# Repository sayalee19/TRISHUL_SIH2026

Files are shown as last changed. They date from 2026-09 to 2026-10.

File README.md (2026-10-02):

## Ready Prototype Images
<table width="100%" style="border-collapse: collapse; border: none;">
  <tr>
    <!-- Left Image and Caption -->
    <td align="left" style="border: none; width: 50%;">
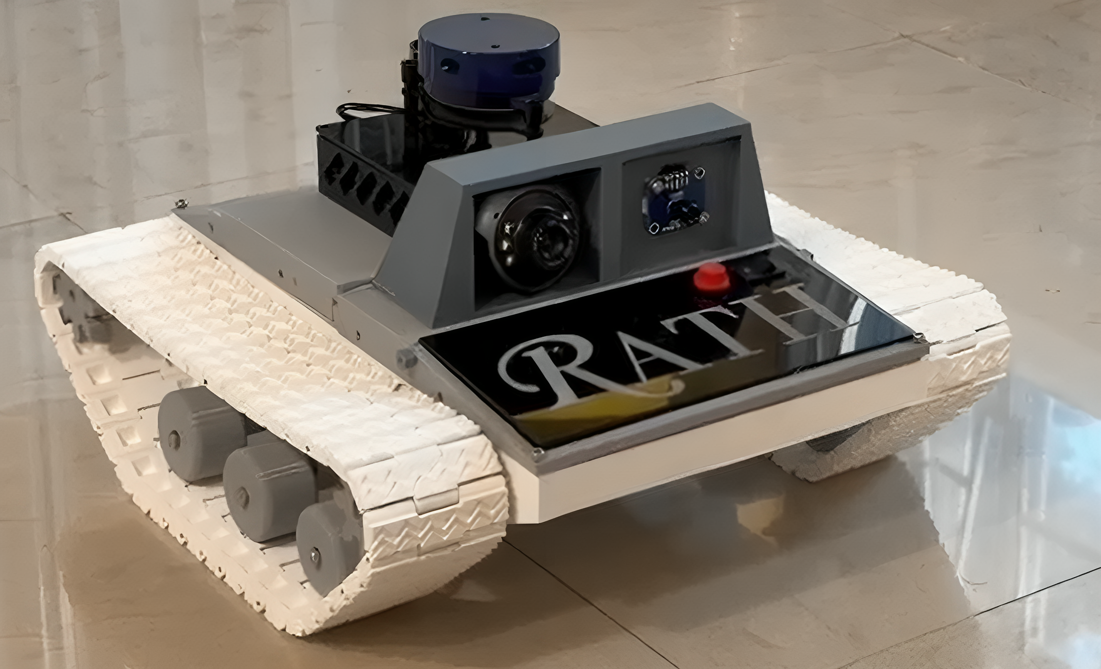
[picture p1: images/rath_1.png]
Rath-1
      <br>
      <small>RATH</small>
    </td>
    <!-- Right Image and Caption -->
    <td align="right" style="border: none; width: 50%;">
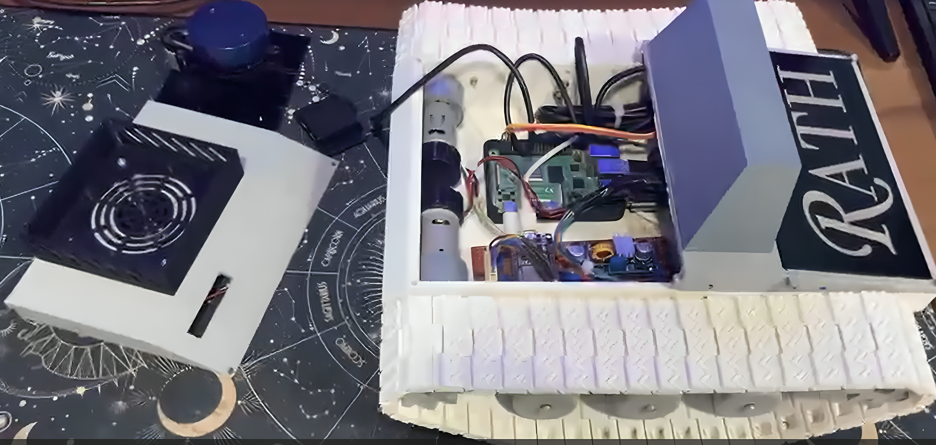
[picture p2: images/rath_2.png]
Rath-2
      <br>
      <small>RATH- Internal View</small>
    </td>
  </tr>
</table>
<table width="100%" style="border-collapse: collapse; border: none;">
  <tr>
    <!-- Left Image and Caption -->
    <td align="left" style="border: none; width: 50%;">
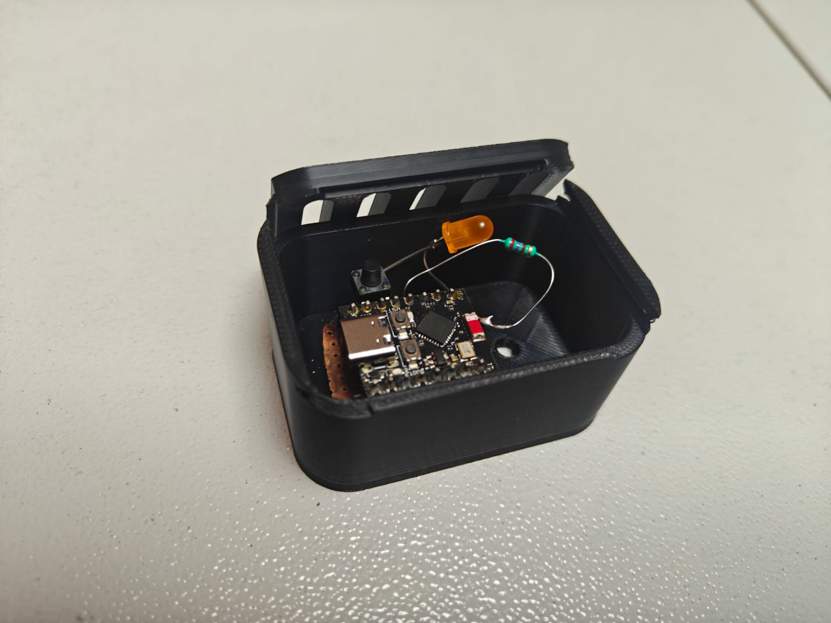
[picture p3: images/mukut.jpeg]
mukut
      <br>
      <small>MUKUT</small>
    </td>
    <!-- Right Image and Caption -->
    <td align="right" style="border: none; width: 50%;">
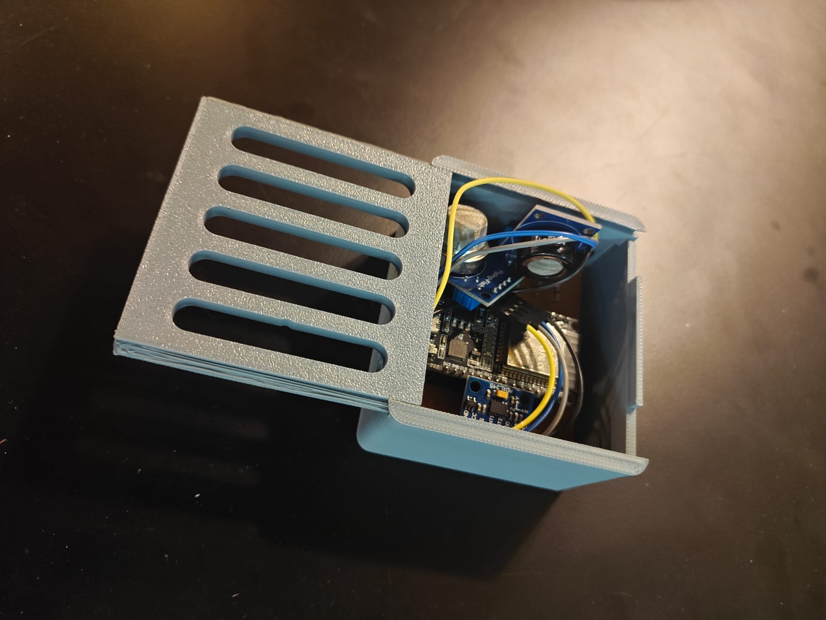
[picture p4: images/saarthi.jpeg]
Saarthi
      <br>
      <small>SAARTHI</small>
    </td>
  </tr>
</table>

<br clear="both" />

<div align="center" style="margin-top: 20px;">
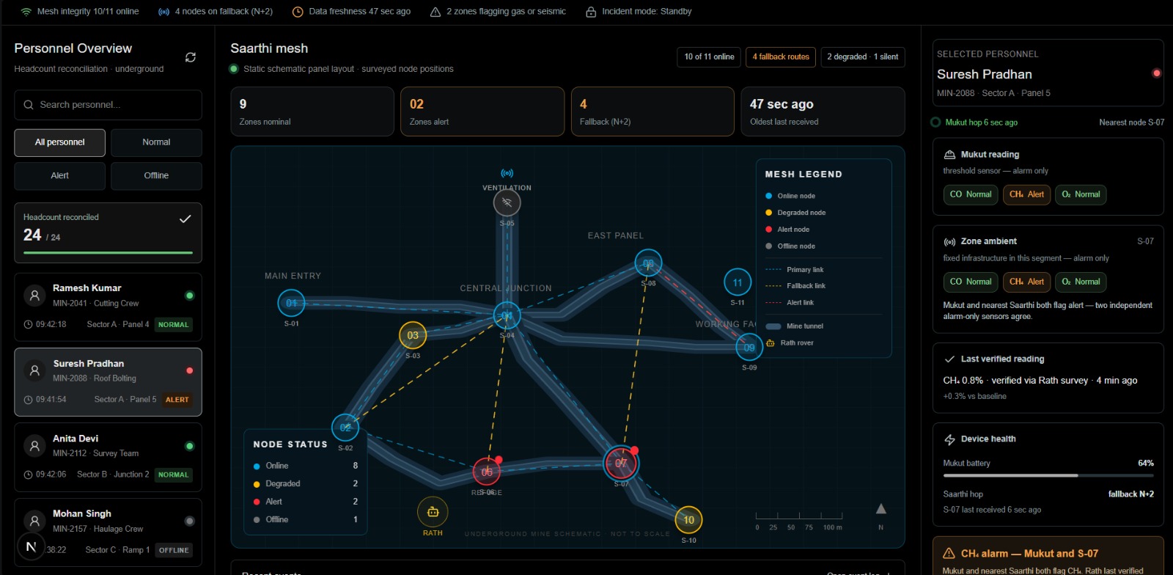
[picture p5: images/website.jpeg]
WEBSITE
  
  <br>
  <small>Overview of the Website Dashboard</small>
</div>

## Problem Statement
To assist rescue teams during emergencies in underground coal mines, providing them with real time information of the underground conditions and reducing response delays.

## Solution Proposed

Underground coal mining remains one of the most hazardous industrial environments in the world, and the danger compounds sharply the moment something goes wrong. Toxic gas accumulation, flooding, tunnel or roof collapse, and near-zero visibility are everyday operational risks, but the real crisis begins after an incident: rescue teams typically have to enter an area they know almost nothing about, using safety infrastructure that was often destroyed in the same event they're responding to. TRISHUL is built around the observation that the mine already has plenty of monitoring and communication equipment, but almost all of it depends on fixed wiring and infrastructure, which means it fails at exactly the moment it's needed most, when a tunnel collapse severs it. TRISHUL's design goal is to build a system that keeps functioning after the primary infrastructure has been physically destroyed. The name reflects this directly-  like a trident, the system is only complete and effective when its three separate units work together as one weapon against the problem, rather than as three independent gadgets.

Unit One:  Mukut (the worn identity and locator unit). Mukut is a helmet-mounted module worn continuously by every miner during their shift. It serves two distinct functions that solve different problems and use different mechanisms. The first is live tracking: each Mukut unit periodically broadcasts a short low-power beacon signal using ESPNOW broadcast mode using an ESP32C3 (containing its unique ID) that nearby Sarthi nodes pick up. This periodic broadcast is deliberately low-frequency (on the order of once every few minutes) to conserve battery across a full shift, and the broadcast timing includes a small randomised jitter so that if two helmets happen to power on at nearly the same moment, they don't end up permanently transmitting in lockstep and repeatedly colliding. The second function is physical identification during actual recovery. If a miner is unconscious, or their helmet's battery has died, or the local network is down, there is no live signal to query. For this reason, Mukut also carries a passive NFC/RFID tag, which requires no onboard power at all and can be read by a rescuer's handheld reader simply by being close to it- carrying the worker's ID,, and any critical medical flags. This is a deliberate, low-power fallback layered underneath the active tracking system.

Unit Two: Sarthi (the fixed monitoring and mesh backbone). Sarthi nodes are installed at intervals along the mine's tunnels, at positions that are surveyed and recorded once during installation. They perform three jobs simultaneously. First, they listen for Mukut beacons and report what they hear to the surface, which is how miner location is estimated. To receive the Mukut beacons, they have ESP32 in receive mode for ESPNOW broadcast. Sarthi nodes do trilateration- two or three nearby nodes each report the signal strength (RSSI) at which they received the same beacon, the surface system can combine these readings to produce a rough position estimate, generally biased toward whichever node heard the signal strongest. 
Second, Sarthi continuously monitors the mine environment using onboard sensors- general-purpose gas sensors for baseline monitoring, and seismic/vibration sensors capable of detecting the ground motion associated with a roof or tunnel failure. Rather than streaming raw sensor values constantly, each node processes its readings locally and only raises a flag when values move meaningfully beyond an established baseline, thus keeping  routine network traffic small and making genuine anomalies stand out clearly at the surface dashboard. 
Third, Sarthi nodes relay all of this information- miner locations and sensor flags, hop by hop through a self-organising wireless mesh network back to a surface gateway. This mesh is designed so that no single node is a single point of failure for everything behind it: each node simply broadcasts what it knows, listens for what its neighbours are broadcasting, and forwards new information onward, using packet IDs and a hop-limit to prevent the same message being endlessly re-broadcast in loops. If a node goes offline, its neighbours simply stop hearing from it and traffic reroutes through whatever alternative path still exists, without needing to be manually reconfigured. A collapse event is inferred not from a single sensor reading in isolation, but from a correlated pattern- several adjacent Sarthi nodes going silent at once, together with a seismic spike reported by nodes still alive nearby. 
These Sarthi nodes are powered normally through the power cables that are already present in the mines. They also have an additional battery backup in case the power lines are disrupted in an event of a collapse.

Unit Three: Rath (the autonomous rescue rover). Rath is only deployed after the surface command centre confirms a likely collapse event or gas leak from the Sarthi network's combined signals. It is a tracked rover specifically chosen over wheels because tracks distribute weight and maintain traction across loose rubble and uneven collapsed terrain, which wheeled platforms handle poorly. For navigation, Rath uses LIDAR-based SLAM (simultaneous localisation and mapping), allowing it to build a live map of the collapsed area as it drives and navigate autonomously without needing a pre-existing map of the zone. 
Rath carries a dedicated multi-gas sensing unit, distinct from Sarthi's generic sensors, because at this stage the mission needs precise, gas-specific readings rather than a simple threshold flag. This unit detects CO, CH4, propane, ammonia, and H2S individually, and an onboard processor calculates standard occupational safety metrics- IDLH (Immediately Dangerous to Life or Health) and STEL (Short-Term Exposure Limit) values, directly from these readings using established formulas, so that rescue teams receive an already-interpreted hazard assessment rather than raw numbers they'd have to manually cross-reference.
Rath also carries a thermal camera and a standard visual camera; because visibility underground after a collapse is often extremely poor (dust, smoke, low light), the video and thermal streams are processed by AI-based image restoration/enhancement algorithms at the surface, to improve usability for both the human operators watching the feed and any onboard person-detection algorithms trying to automatically spot survivors in the footage, rather than relying solely on a human operator to notice something in a degraded feed.
All the measurements and visuals obtained from the Rath as well as the miner locations obtained from the Mukut and transmitted via Sarthi network would then be visible on a central dashboard at the surface, in real time.

TRISHUL proposes a resilient, layered safety and rescue architecture designed to remain operational when conventional mine infrastructure is compromised. By integrating Mukut's persistent worker identification and localisation, Sarthi's distributed environmental monitoring and self-organising communication backbone, and Rath's autonomous reconnaissance and hazard-assessment capabilities, the system establishes a continuous chain from detection and localisation to assessment and response. Its distributed architecture ensures that the failure of individual nodes or communication links does not necessarily result in the failure of the entire system, while the combination of active and passive identification, local sensor intelligence, mesh communication, autonomous mapping, multi-gas analysis, and enhanced visual and thermal perception provides redundancy across multiple stages of an emergency. Rather than attempting to replace existing mine safety infrastructure, TRISHUL is designed as a resilient layer that takes over when that infrastructure becomes unavailable. Ultimately, the system aims to reduce uncertainty during the most critical phase of a mining disaster, enabling rescue teams to understand where the incident has occurred, what hazards are present, and how the affected area can be approached before human responders are exposed to unnecessary risk.

## Technical Approach 
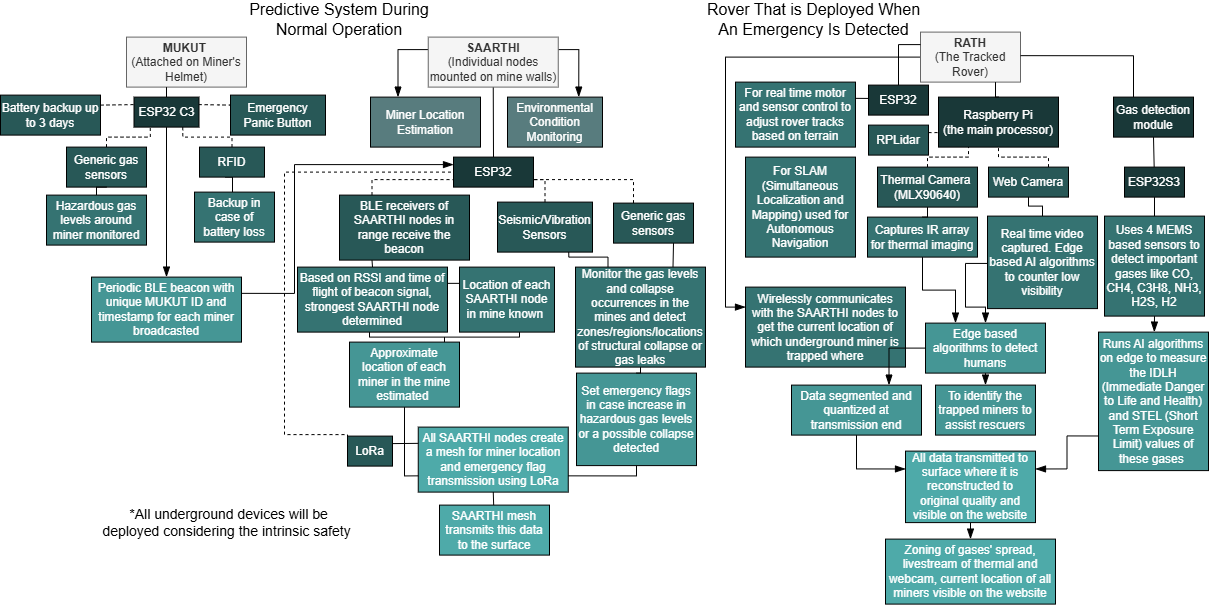
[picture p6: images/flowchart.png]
Technical Approach


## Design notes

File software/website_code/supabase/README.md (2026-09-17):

# Mine telemetry data model

This project is designed around a mine safety stack where:

- Rath is the emergency-capable relay and camera platform.
- Mukut is mounted on each worker's helmet and reports location and gas.
- Sarthi nodes are fixed anchor modules in the mine and provide BLE-based relative positioning and threshold gas/vibration alerts.
- Live RGB and thermal feeds are only available when Rath is active.

## Core entities

1. `mine_sites`
   - one row per mine or section
2. `zones`
   - logical mine sections like panel, ramp, junction, roadway
3. `workers`
   - worker roster, no medical or health fields included
4. `devices`
   - all hardware devices: rath, mukut, sarthi, camera
5. `worker_locations`
   - periodic worker coordinates relative to Sarthi anchor nodes
6. `gas_readings`
   - gas sensor data from Rath/Mukut/Sarthi with reliable vs threshold-only states
7. `vibration_events`
   - seismic and vibration events from Sarthi nodes
8. `camera_streams`
   - RGB and thermal streams from Rath
9. `alerts`
   - system-level alert events used for command center notifications

## Important rules

- Do not store health metrics like pulse, SpO2, or temperature in the worker table.
- Treat `gas_readings` as two visual categories in the UI:
  - threshold-only chips from Mukut (helmet MQ) and Saarthi (fixed MQ): Normal/Alert, never shown as a calibrated number
  - reliable readings from Rath surveys only: these are the one place a real value is shown, with `baseline_value` / `deviation_pct` when available
- Saarthi nodes are ordered by `devices.position_index` (physical tunnel order). `routing_mode` is `primary` (N+1) or `fallback` (N+2).
- Track device ownership and zone context so the UI can show which worker is near which Sarthi module.
- Keep `camera_streams` separate from `gas_readings`, because the camera lane only operates when Rath is active.

## Recommended Supabase usage

- Use Postgres tables for durable storage.
- Use Supabase Realtime on `worker_locations`, `gas_readings`, `vibration_events`, `alerts`, and `camera_streams` for live command-center updates.
- Keep worker-facing cards focused on:
  - worker identity and zone
  - last location update
  - recent gas status
  - recent alert severity
  - camera availability when Rath is online

## Example data flow

- Mukut on helmet emits gas + location.
- Worker location is computed relative to nearby Sarthi BLE anchors.
- Sarthi emits threshold-only gas and vibration alerts.
- Rath emits reliable gas values and live camera streams.
- The UI combines these streams into a single safety view for the operator.

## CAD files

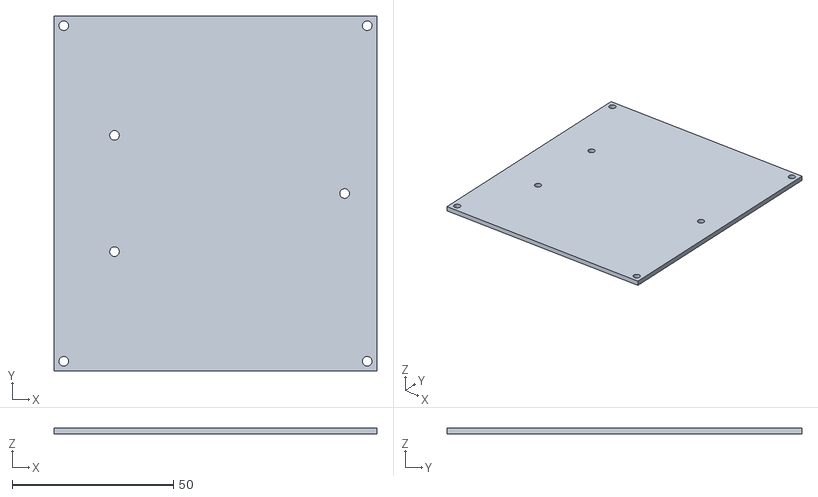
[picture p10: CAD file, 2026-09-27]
cad_files/Gas_lid.stl
100.0 x 110.0 x 2.00

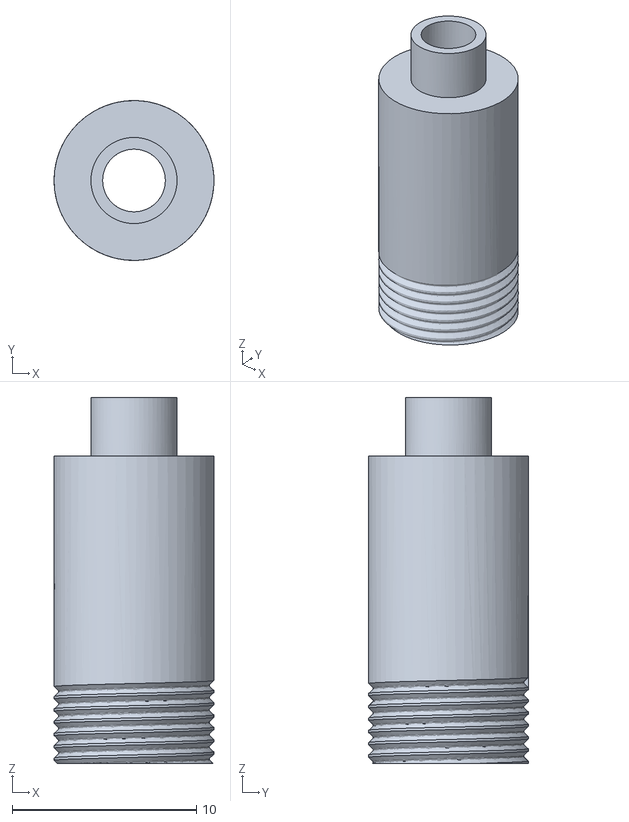
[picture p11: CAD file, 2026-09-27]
cad_files/Shock Absorber/Shock_frame_final.stl
8.67 x 8.67 x 19.8

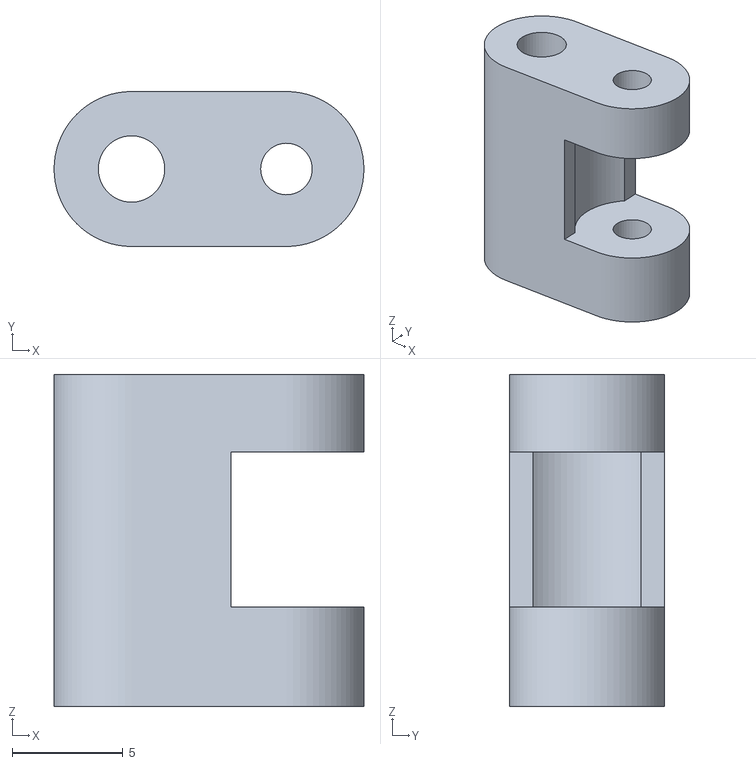
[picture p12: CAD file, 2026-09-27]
cad_files/Tracks/Shock_link.stl
14.0 x 7.00 x 15.0

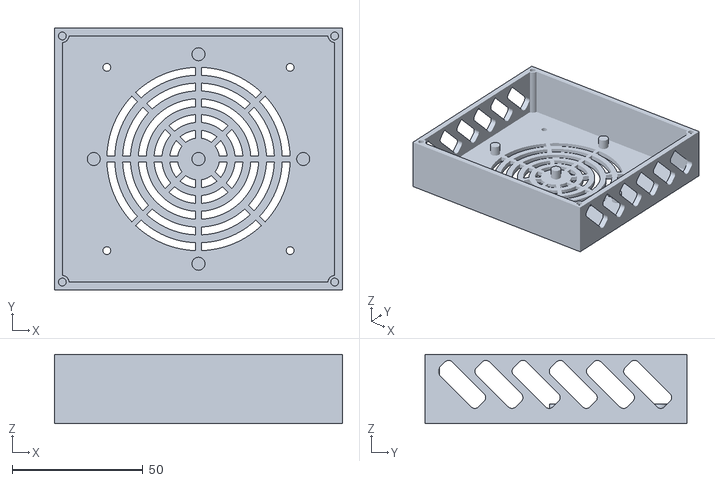
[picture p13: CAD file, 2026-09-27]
cad_files/Gas_Bottom.stl
110.0 x 100.0 x 26.5

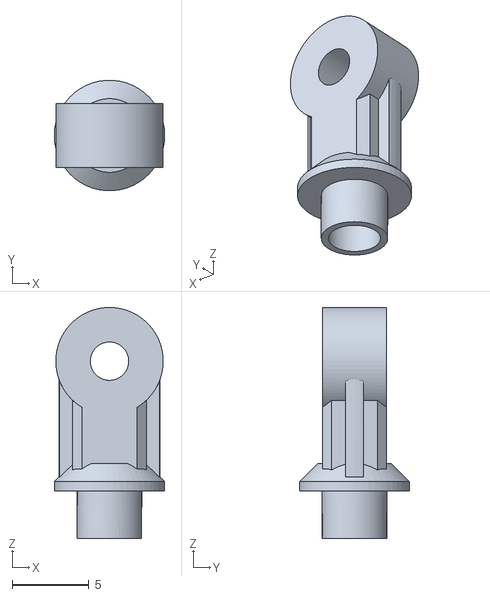
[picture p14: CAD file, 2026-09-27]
cad_files/Shock Absorber/Shock_bottom_final.stl
7.20 x 7.19 x 15.1

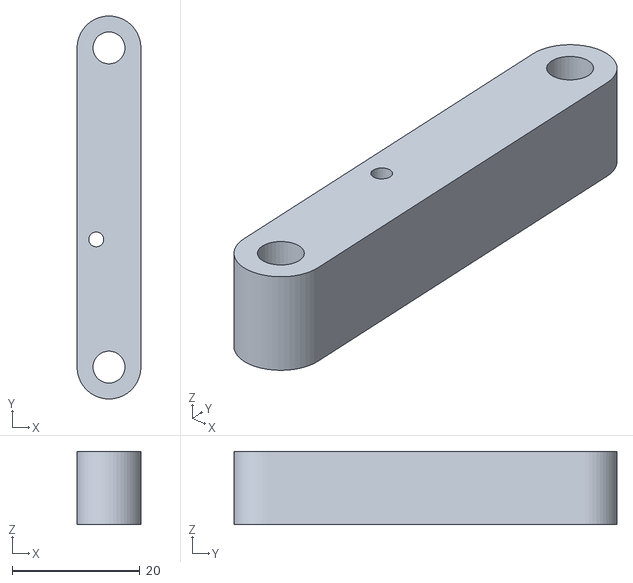
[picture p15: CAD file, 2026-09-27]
cad_files/Tracks/Wheel_link_right.stl
10.0 x 60.0 x 11.5

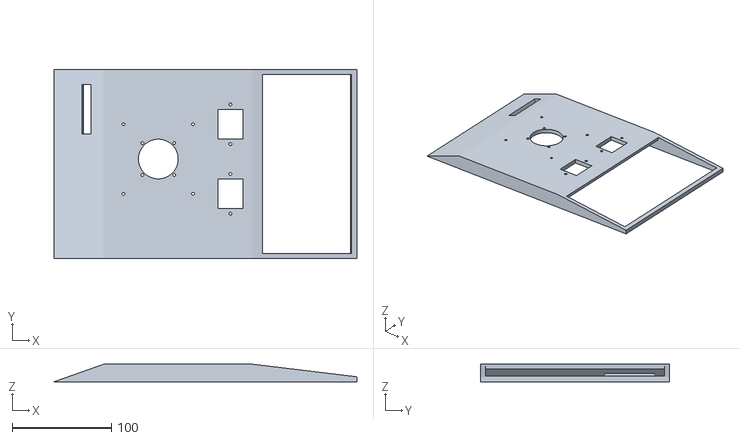
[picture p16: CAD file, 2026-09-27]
cad_files/Rover_top_v2.stl
305.0 x 190.0 x 17.7

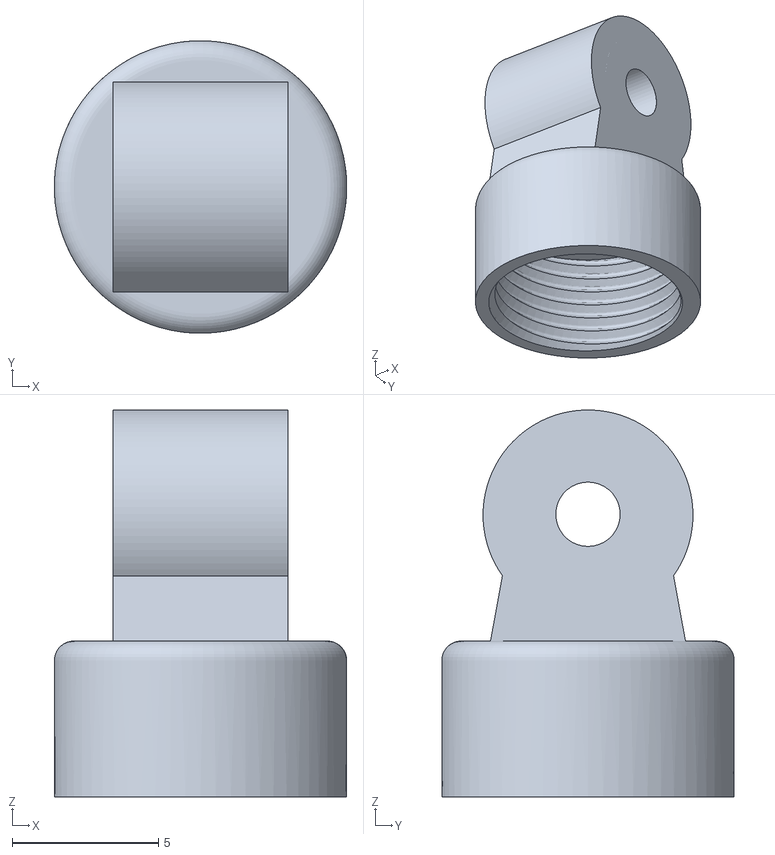
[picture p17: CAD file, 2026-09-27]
cad_files/Shock Absorber/shock_top.stl
10.0 x 10.0 x 13.2

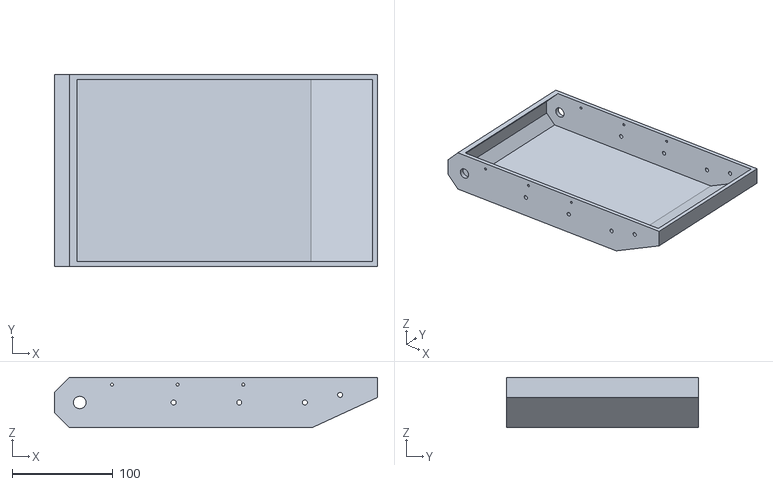
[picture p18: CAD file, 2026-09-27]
cad_files/Rover_body.stl
320.0 x 190.0 x 50.0

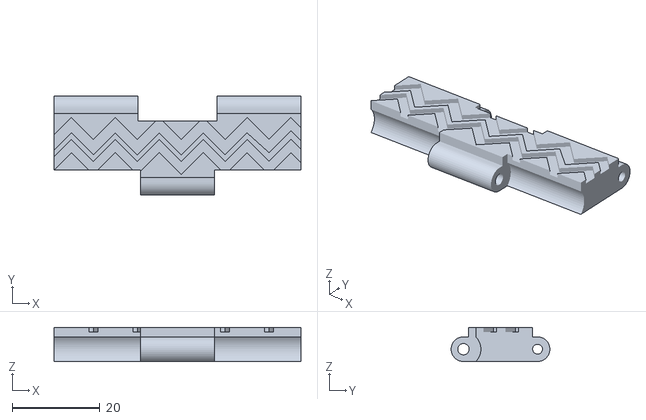
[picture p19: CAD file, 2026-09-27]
cad_files/Tracks/Track_link.stl
56.2 x 22.5 x 7.75

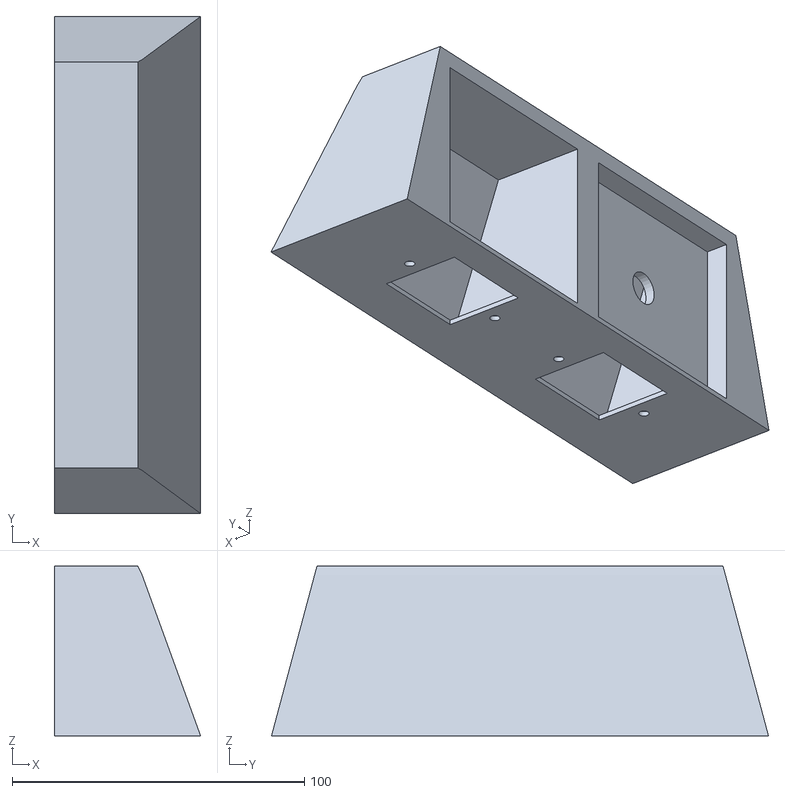
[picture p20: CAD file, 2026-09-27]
cad_files/Camera_frame.stl
50.0 x 170.0 x 58.0

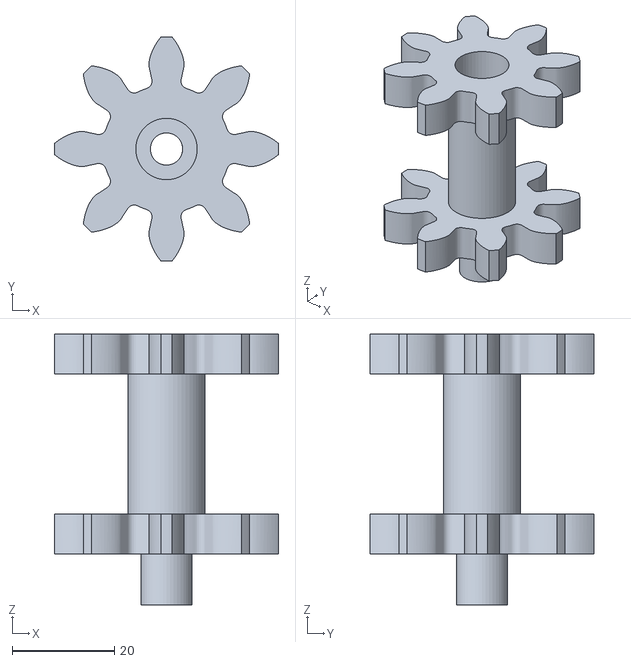
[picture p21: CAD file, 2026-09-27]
cad_files/Tracks/Front_gear_sprocket.stl
43.7 x 43.7 x 52.9

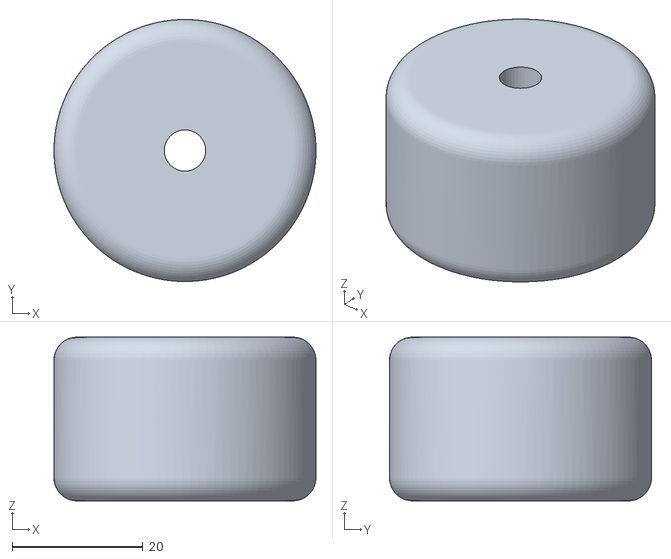
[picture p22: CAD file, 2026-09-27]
cad_files/Tracks/Roller.stl
40.0 x 40.0 x 25.0

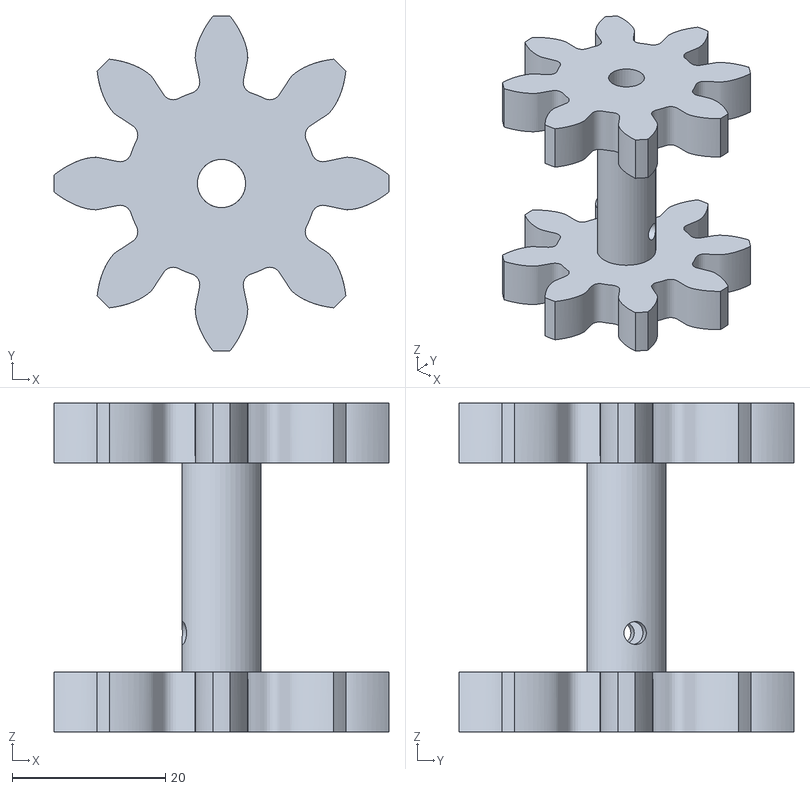
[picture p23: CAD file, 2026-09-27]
cad_files/Tracks/Rear_Gear_sprocket.stl
43.7 x 43.7 x 42.9

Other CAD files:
cad_files/Tracks/Wheel_link_left.stl

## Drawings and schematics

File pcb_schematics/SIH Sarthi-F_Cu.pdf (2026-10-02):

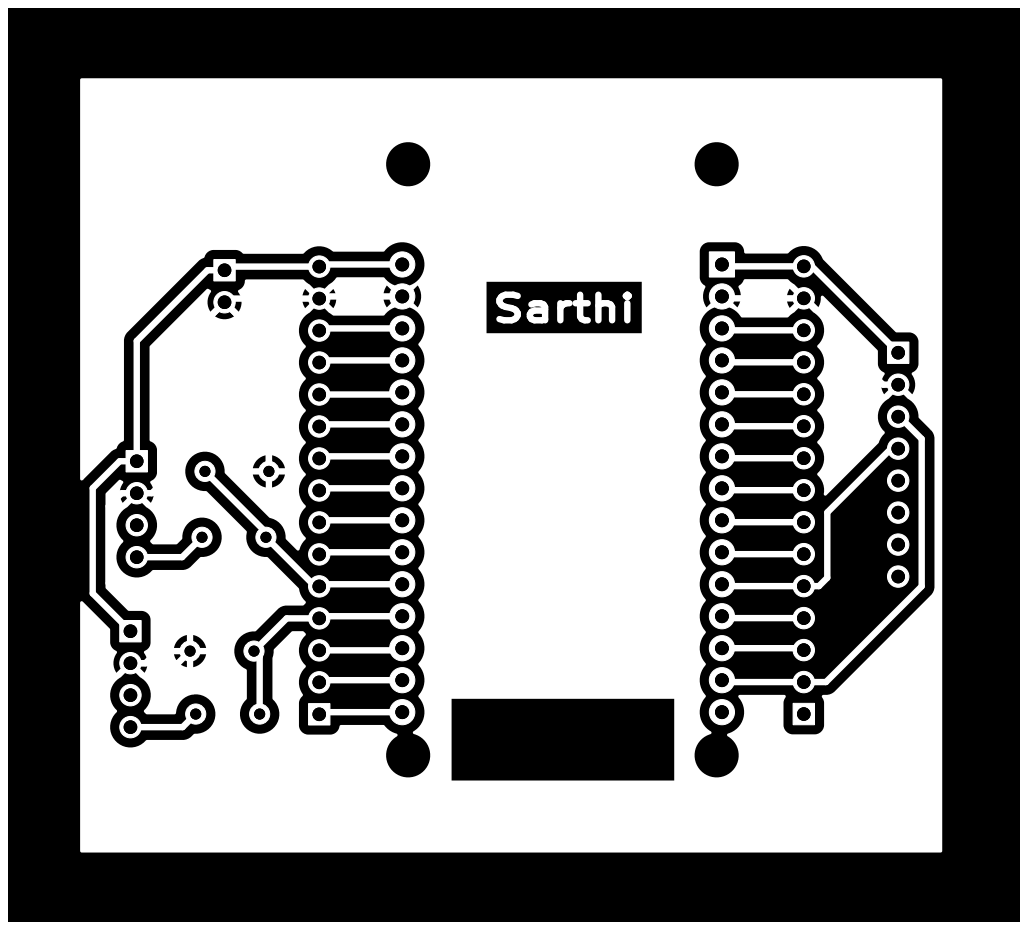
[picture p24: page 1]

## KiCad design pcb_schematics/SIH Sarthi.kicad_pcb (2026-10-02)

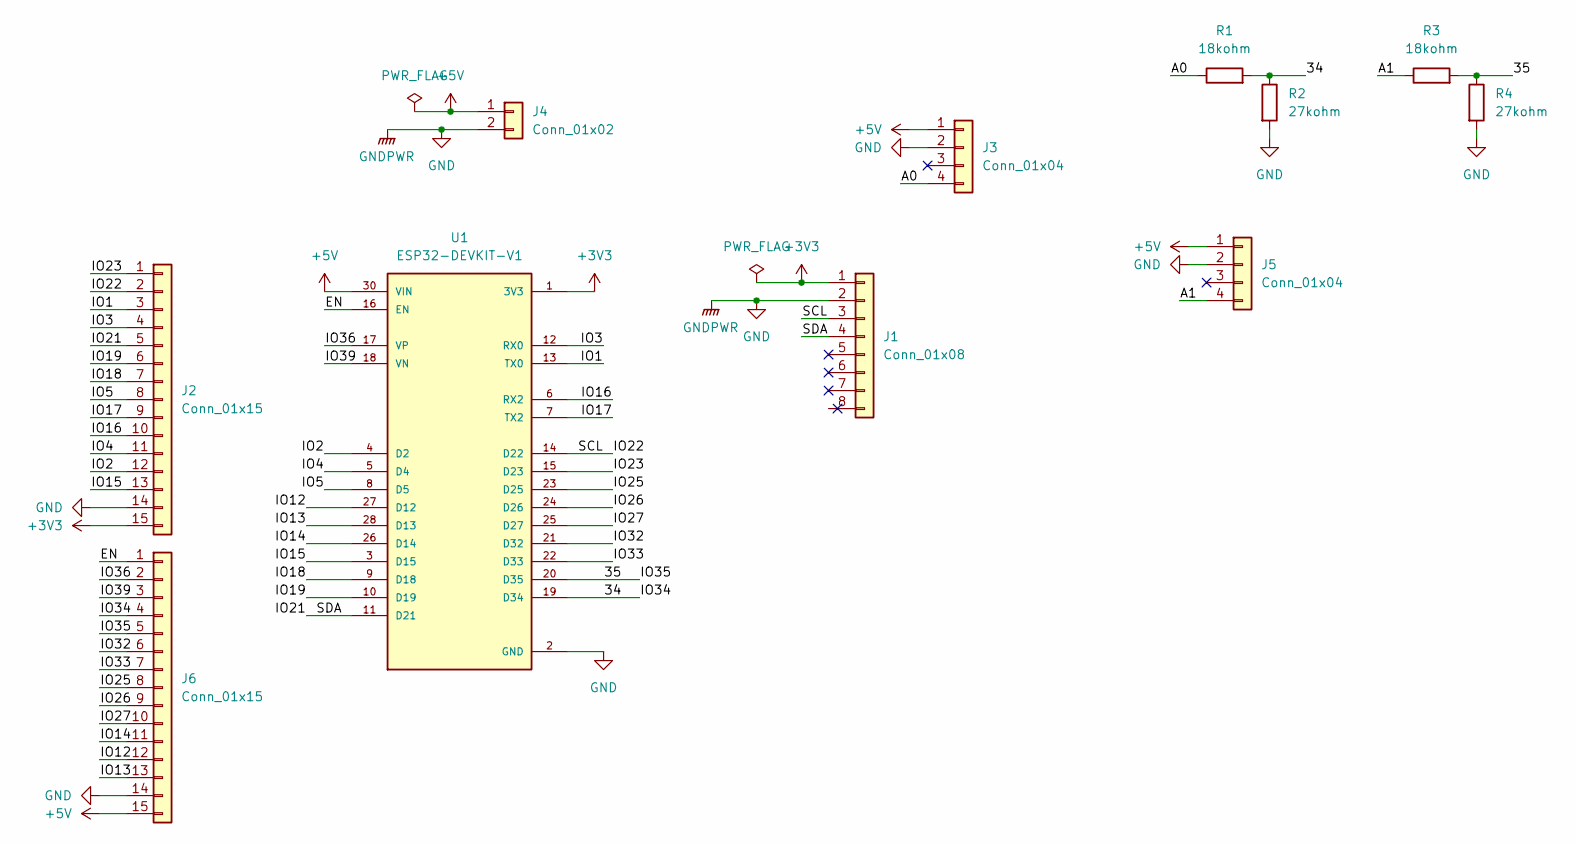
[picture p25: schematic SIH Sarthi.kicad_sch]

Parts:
J1: Conn_01x08; PinHeader_1x08_P2.54mm_Vertical
J2, J6: Conn_01x15; PinHeader_1x15_P2.54mm_Vertical
J3, J5: Conn_01x04; PinHeader_1x04_P2.54mm_Vertical
J4: Conn_01x02; PinSocket_1x02_P2.54mm_Vertical
R1, R3: 18kohm; R_Axial_DIN0207_L6.3mm_D2.5mm_P5.08mm_Vertical
R2, R4: 27kohm; R_Axial_DIN0207_L6.3mm_D2.5mm_P5.08mm_Vertical
U1: ESP32-DEVKIT-V1; MODULE_ESP32_DEVKIT_V1; PARTREV N/A

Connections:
+3V3: J1.1, J2.15, U1.1 (3V3)
+5V: J3.1, J4.1, J5.1, J6.15, U1.30 (VIN)
/34: J6.4, R1.2, R2.1, U1.19 (D34)
/35: J6.5, R3.2, R4.1, U1.20 (D35)
/A0: J3.4, R1.1
/A1: J5.4, R3.1
/EN: J6.1, U1.16 (EN)
/IO1: J2.3, U1.13 (TX0)
/IO2: J2.12, U1.4 (D2)
/IO3: J2.4, U1.12 (RX0)
/IO4: J2.11, U1.5 (D4)
/IO5: J2.8, U1.8 (D5)
/IO12: J6.12, U1.27 (D12)
/IO13: J6.13, U1.28 (D13)
/IO14: J6.11, U1.26 (D14)
/IO15: J2.13, U1.3 (D15)
/IO16: J2.10, U1.6 (RX2)
/IO17: J2.9, U1.7 (TX2)
/IO18: J2.7, U1.9 (D18)
/IO19: J2.6, U1.10 (D19)
/IO21: J1.4, J2.5, U1.11 (D21)
/IO22: J1.3, J2.2, U1.14 (D22)
/IO23: J2.1, U1.15 (D23)
/IO25: J6.8, U1.23 (D25)
/IO26: J6.9, U1.24 (D26)
/IO27: J6.10, U1.25 (D27)
/IO32: J6.6, U1.21 (D32)
/IO33: J6.7, U1.22 (D33)
/IO36: J6.2, U1.17 (VP)
/IO39: J6.3, U1.18 (VN)
GND: J1.2, J2.14, J3.2, J4.2, J5.2, J6.14, R2.2, R4.2, U1.2 (GND), U1.29 (GND)

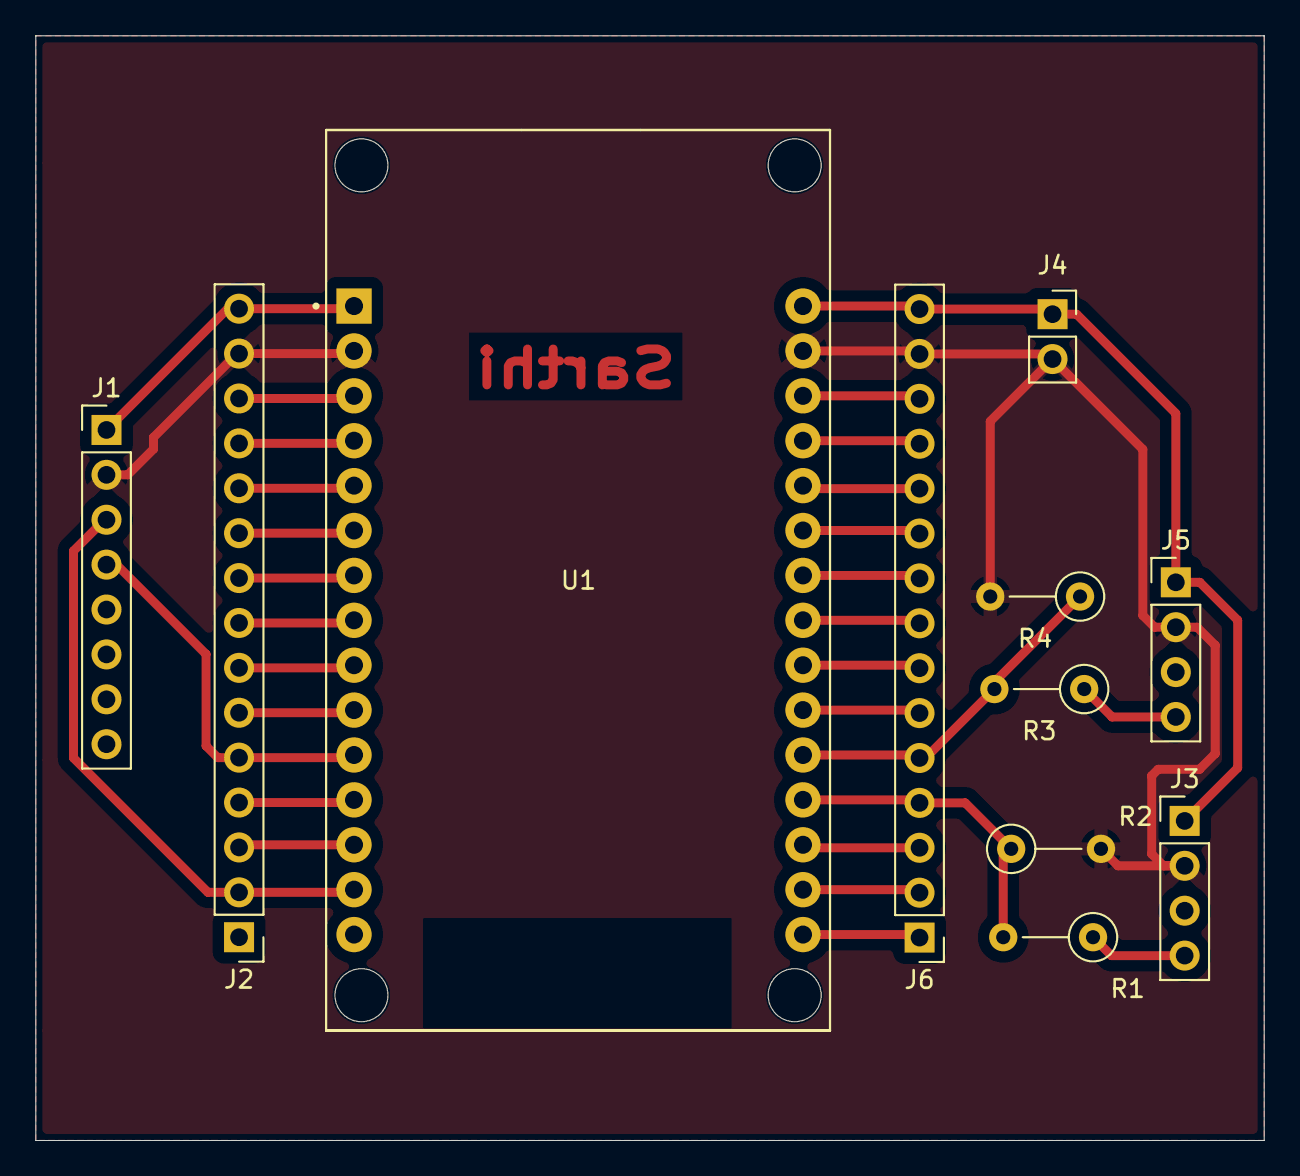
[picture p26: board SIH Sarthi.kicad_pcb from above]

Board: 2 copper layers, 69.5 x 62.5 mm, 11 parts (0 on the bottom side), 31 nets.

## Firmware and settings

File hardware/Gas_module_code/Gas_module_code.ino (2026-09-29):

#include <Arduino.h>
#include <Preferences.h>
#include <DHT.h>
#include <Wire.h>
#include <Adafruit_GFX.h>
#include <Adafruit_SSD1306.h>

// ---------------------- SHARED ----------------------
Adafruit_SSD1306 display(128, 64, &Wire, -1);
const int DHT_PIN = 10;
#define DHTTYPE DHT11
DHT dht(DHT_PIN, DHTTYPE);

const unsigned long SAMPLE_INTERVAL_MS = 2000;
const int   SAMPLES_PER_READING = 20;
const int   CALIBRATION_SAMPLES = 50;
const float EMA_ALPHA = 0.2;
const unsigned long OLED_SWITCH_MS = 5000;
unsigned long g_lastOledSwitch = 0;
bool g_oledPageA = true; // true = H2S/H2/CH4, false = CO/NH3/Propane
const unsigned long OLED_REDRAW_MS = 200;
unsigned long g_lastOledDraw = 0;

// Last-known values, updated once per SAMPLE_INTERVAL_MS cycle, read by
// the OLED on its own independent 5s timer -- decoupled on purpose, since
// the display shouldn't block or be blocked by the sensor sample loop.
float g_disp_h2s = -2.0, g_disp_h2 = -2.0, g_disp_ch4 = -2.0;
float g_disp_co  = -2.0, g_disp_nh3 = -2.0, g_disp_prop = -2.0;

Preferences prefs;
unsigned long g_lastSampleTime = 0;

struct DhtReading { float tempC; float rh; bool valid; };

DhtReading readDHT() {
  DhtReading r;
  r.tempC = dht.readTemperature();
  r.rh = dht.readHumidity();
  r.valid = !(isnan(r.tempC) || isnan(r.rh));
  return r;
}

// Turns a value or sentinel into a short display string -- same sentinel
// convention as your Serial output, just condensed for a small screen.
String fmtPPM(float v) {
  if (v == -2.0) return "warm";
  if (v == -1.0) return "n/cal";
  if (v == -3.0) return "dht!";
  if (v == -4.0) return "n/dig";
  return String(v, 1);
}
void updateOLED() {
  unsigned long now = millis();
  if (now - g_lastOledSwitch >= OLED_SWITCH_MS) {
    g_lastOledSwitch = now;
    g_oledPageA = !g_oledPageA;
  }
  if (now - g_lastOledDraw < OLED_REDRAW_MS) return; // <-- add this guard
  g_lastOledDraw = now;

  display.clearDisplay();
  display.setTextSize(1);
  display.setTextColor(SSD1306_WHITE);
  display.setCursor(0, 0);

  if (g_oledPageA) {
    display.println("H2S:  " + fmtPPM(g_disp_h2s) + " ppm");
    display.println("H2:   " + fmtPPM(g_disp_h2)  + " ppm");
    display.println("CH4:  " + fmtPPM(g_disp_ch4) + " ppm");
  } else {
    display.println("CO:   " + fmtPPM(g_disp_co)   + " ppm");
    display.println("NH3:  " + fmtPPM(g_disp_nh3)  + " ppm");
    display.println("Prop: " + fmtPPM(g_disp_prop) + " ppm");
  }
  display.display();
}

// ---------------------- H2S (GM-602B) ----------------------

namespace H2S {
  // *** VERIFY against your actual measured supply, not the datasheet's 5.0V test condition. ***
  const float VCC_MV  = 3300.0;
  const float RL_KOHM = 3.0;  // confirmed from Fermion board schematic (R2)

  // NOTE: pin 33 was in your original code with a comment claiming ESP32-S3
  // ADC1 -- on the S3, ADC1 channels are GPIO1-10, so 33 may actually be an
  // S2/classic-ESP32 pin mapping left over from a template. Double-check
  // against your actual board's pinout before trusting this.
  const int SENSOR_PIN = 35;

  const unsigned long WARMUP_TIME_MS = 120000; // assumes sensor already aged (48h/72h/168h per storage time)
  const float PPM_MIN_VALID = 0.5;
  const float PPM_MAX_VALID = 50.0;

  struct CurvePoint { float rsr0; float ppm; };
  const CurvePoint CURVE[] = {
    {0.6078f,  1.0176f}, {0.5623f,  1.4411f}, {0.5367f,  2.0409f},
    {0.4927f,  2.9411f}, {0.4630f,  3.8853f}, {0.4384f,  5.0440f},
    {0.3871f,  6.4352f}, {0.3262f,  9.7707f}, {0.2603f, 14.8349f},
    {0.2211f, 19.5971f}, {0.1907f, 24.1475f}, {0.1697f, 30.2767f},
    {0.1354f, 38.6280f}, {0.1073f, 50.1478f},
  };
  const int CURVE_LEN = sizeof(CURVE) / sizeof(CURVE[0]);

  const float TEMP_AXIS_C[7] = {-10, 0, 10, 20, 30, 40, 50};
  const float HUM_AXIS_PCT[3] = {30, 60, 85};  // reference RH = 55%
  const float CORRECTION_TABLE[3][7] = {
    { 1.71, 1.57, 1.46, 1.37, 1.13, 1.01, 0.89 },
    { 1.48, 1.32, 1.27, 1.09, 0.98, 0.87, 0.72 },
    { 1.28, 1.15, 1.09, 0.91, 0.86, 0.72, 0.67 },
  };



  float g_R0_kohm = -1.0;
  float g_ema_ppm = -1.0;
  unsigned long g_bootTime = 0;
  bool g_warmupDone = false;

  float readVoltage_mV(int n) {
    long sum = 0;
    for (int i = 0; i < n; i++) { sum += analogReadMilliVolts(SENSOR_PIN); delay(5); }
    return (float)sum / n;
  }

  float voltageToRs_kohm(float vout_mV) {
    if (vout_mV >= VCC_MV - 1.0) return 0.0001;
    if (vout_mV < 1.0) vout_mV = 1.0;
    return RL_KOHM * (VCC_MV - vout_mV) / vout_mV;
  }

  float tempHumidityFactor(float tempC, float rh) {
    if (tempC < TEMP_AXIS_C[0]) tempC = TEMP_AXIS_C[0];
    if (tempC > TEMP_AXIS_C[6]) tempC = TEMP_AXIS_C[6];
    if (rh < HUM_AXIS_PCT[0]) rh = HUM_AXIS_PCT[0];
    if (rh > HUM_AXIS_PCT[2]) rh = HUM_AXIS_PCT[2];
    int ti = 0; while (ti < 5 && TEMP_AXIS_C[ti+1] < tempC) ti++;
    float t0=TEMP_AXIS_C[ti], t1=TEMP_AXIS_C[ti+1];
    float ft = (t1>t0)?(tempC-t0)/(t1-t0):0.0;
    int hi = 0; while (hi < 1 && HUM_AXIS_PCT[hi+1] < rh) hi++;
    float h0=HUM_AXIS_PCT[hi], h1=HUM_AXIS_PCT[hi+1];
    float fh = (h1>h0)?(rh-h0)/(h1-h0):0.0;
    float row0 = CORRECTION_TABLE[hi][ti] + ft*(CORRECTION_TABLE[hi][ti+1]-CORRECTION_TABLE[hi][ti]);
    float row1 = CORRECTION_TABLE[hi+1][ti] + ft*(CORRECTION_TABLE[hi+1][ti+1]-CORRECTION_TABLE[hi+1][ti]);
    return row0 + fh*(row1-row0);
  }

  float ratioToPPM(float ratio) {
    if (ratio > 1.0f) ratio = 1.0f;
    if (ratio > CURVE[0].rsr0) {
      float t = (1.0f - ratio) / (1.0f - CURVE[0].rsr0);
      return t * CURVE[0].ppm;
    }
    if (ratio <= CURVE[CURVE_LEN-1].rsr0) return CURVE[CURVE_LEN-1].ppm;
    for (int i = 0; i < CURVE_LEN - 1; i++) {
      if (ratio <= CURVE[i].rsr0 && ratio >= CURVE[i+1].rsr0) {
        float logR = log10(ratio);
        float t = (logR - log10(CURVE[i].rsr0)) / (log10(CURVE[i+1].rsr0) - log10(CURVE[i].rsr0));
        float logP = log10(CURVE[i].ppm) + t*(log10(CURVE[i+1].ppm) - log10(CURVE[i].ppm));
        return pow(10.0f, logP);
      }
    }
    return CURVE[CURVE_LEN-1].ppm;
  }

  bool calibrateR0() {
    if (!g_warmupDone) { Serial.println(F("[H2S CAL REFUSED] still warming up")); return false; }
    float sumRs = 0; int valid = 0;
    for (int i = 0; i < CALIBRATION_SAMPLES; i++) {
      float rawRs = voltageToRs_kohm(readVoltage_mV(1));
      DhtReading d = readDHT();
      if (!d.valid) { delay(20); continue; }
      float corrected = rawRs * tempHumidityFactor(d.tempC, d.rh);
      if (corrected > 0.001 && corrected < 100000.0) { sumRs += corrected; valid++; }
      delay(20);
    }
    if (valid < CALIBRATION_SAMPLES/2) { Serial.println(F("[H2S CAL FAILED]")); return false; }
    g_R0_kohm = sumRs / valid;
    prefs.putFloat("h2s_r0", g_R0_kohm);
    Serial.print(F("H2S calibrated. R0=")); Serial.println(g_R0_kohm, 4);
    return true;
  }

  float getPPM(DhtReading &d) {
    if (!g_warmupDone) return -2.0;
    if (g_R0_kohm <= 0.0) return -1.0;
    if (!d.valid) return -3.0;
    float corrected = voltageToRs_kohm(readVoltage_mV(SAMPLES_PER_READING)) * tempHumidityFactor(d.tempC, d.rh);
    float ratio = corrected / g_R0_kohm;
    if (ratio <= 0.0001) ratio = 0.0001;
    float ppm = ratioToPPM(ratio);
    if (ppm > PPM_MAX_VALID) ppm = PPM_MAX_VALID;
    g_ema_ppm = (g_ema_ppm < 0) ? ppm : (EMA_ALPHA*ppm + (1.0-EMA_ALPHA)*g_ema_ppm);
    return g_ema_ppm;
  }

  void begin() {
    analogSetPinAttenuation(SENSOR_PIN, ADC_11db);
    g_R0_kohm = prefs.getFloat("h2s_r0", -1.0);
    g_bootTime = millis();
  }

  void updateWarmup() {
    if (!g_warmupDone && millis() - g_bootTime >= WARMUP_TIME_MS) {
      g_warmupDone = true;
      Serial.println(F("H2S warm-up complete."));
    }
  }
}
// ---------------------- CO (digitized power-law fit) ----------------------
// Rs/R0 = 3.58692 * ppm^(-0.84024), R²=0.996 -- strong fit. Validated range
// (0.94-1023.12 ppm) lines up closely with MiCS-5524's own datasheet-rated
// CO detection range (1-1000ppm), which is a good independent sanity check
// that this digitization is real, unlike the earlier failed attempt.
namespace CO {
  const float VCC_MV  = 3300.0;   // VERIFY against actual wiring
  const float RL_KOHM = 10.0;     // VERIFY against schematic -- shares the MICS-5524 physical sensor if that's what generated this data (see note below)

  const int SENSOR_PIN = 34;      // placeholder -- pick a real free ADC1 pin, distinct from all other gas namespaces

  const unsigned long WARMUP_TIME_MS = 120000; // settle window only, same caveat as all others
  const float PPM_MIN_VALID = 0.94;    // lower bound the fit was validated over
  const float PPM_MAX_VALID = 1023.12; // upper bound the fit was validated over

  const float CURVE_A = 3.58692f;
  const float CURVE_B = -0.84024f;
  const float INV_B   = 1.0f / (-CURVE_B);

  float g_R0_kohm = -1.0;
  float g_ema_ppm = -1.0;
  unsigned long g_bootTime = 0;
  bool g_warmupDone = false;

  float readVoltage_mV(int n) {
    long sum = 0;
    for (int i = 0; i < n; i++) { sum += analogReadMilliVolts(SENSOR_PIN); delay(5); }
    return (float)sum / n;
  }

  float voltageToRs_kohm(float vout_mV) {
    if (vout_mV >= VCC_MV - 1.0) return 0.0001;
    if (vout_mV < 1.0) vout_mV = 1.0;
    return RL_KOHM * (VCC_MV - vout_mV) / vout_mV;
  }

  // No temp/humidity correction -- MiCS-5524's datasheet doesn't publish
  // one, as established earlier.
  float ratioToPPM(float ratio) {
    if (ratio <= 0.0001f) ratio = 0.0001f;
    float ppm = pow(CURVE_A / ratio, INV_B);

    if (ppm < PPM_MIN_VALID) {
      ppm = PPM_MIN_VALID;
    } else if (ppm > PPM_MAX_VALID) {
      Serial.println(F("[CO WARNING] Reading above the power-law fit's validated range -- extrapolating past measured data."));
      ppm = PPM_MAX_VALID;
    }
    return ppm;
  }

  bool calibrateR0() {
    if (!g_warmupDone) { Serial.println(F("[CO CAL REFUSED] still warming up")); return false; }
    float sumRs = 0; int valid = 0;
    for (int i = 0; i < CALIBRATION_SAMPLES; i++) {
      float rs = voltageToRs_kohm(readVoltage_mV(1));
      if (rs > 0.001 && rs < 100000.0) { sumRs += rs; valid++; }
      delay(20);
    }
    if (valid < CALIBRATION_SAMPLES/2) { Serial.println(F("[CO CAL FAILED]")); return false; }
    g_R0_kohm = sumRs / valid;
    prefs.putFloat("co_r0", g_R0_kohm);
    Serial.print(F("CO calibrated. R0=")); Serial.println(g_R0_kohm, 4);
    return true;
  }

  float getPPM() {
    if (!g_warmupDone) return -2.0;
    if (g_R0_kohm <= 0.0) return -1.0;
    float ratio = voltageToRs_kohm(readVoltage_mV(SAMPLES_PER_READING)) / g_R0_kohm;
    float ppm = ratioToPPM(ratio);
    g_ema_ppm = (g_ema_ppm < 0) ? ppm : (EMA_ALPHA*ppm + (1.0-EMA_ALPHA)*g_ema_ppm);
    return g_ema_ppm;
  }

  void begin() {
    analogSetPinAttenuation(SENSOR_PIN, ADC_11db);
    g_R0_kohm = prefs.getFloat("co_r0", -1.0);
    g_bootTime = millis();
  }

  void updateWarmup() {
    if (!g_warmupDone && millis() - g_bootTime >= WARMUP_TIME_MS) {
      g_warmupDone = true;
      Serial.println(F("CO warm-up complete."));
    }
  }
}
// ---------------------- H2 (GMV-2021B) ----------------------

// ---------------------- NH3 (digitized power-law fit) ----------------------
// Rs/R0 = 0.98775 * ppm^(-0.22691), R²=0.987 -- good fit, points span
// ppm 1.26-164.55. Table built by sampling this fitted curve at points
// across that validated range (not raw digitized points, which is fine --
// the fit itself is the trustworthy artifact here, same treatment as CH4).
namespace NH3 {
  const float VCC_MV  = 3300.0;   // VERIFY against actual wiring
  const float RL_KOHM = 10.0;     // VERIFY against this board's schematic -- shares the MICS-5524 physical sensor if that's what generated this data

  const int SENSOR_PIN = 34;      // placeholder -- pick a real free ADC1 pin, distinct from all other gas namespaces

  const unsigned long WARMUP_TIME_MS = 120000; // settle window only, same caveat as all others
  const float PPM_MIN_VALID = 1.26;    // lower bound the fit was validated over
  const float PPM_MAX_VALID = 164.55;  // upper bound the fit was validated over -- not a physical ceiling, just where your data stopped

  const float CURVE_A = 0.98775f;
  const float CURVE_B = -0.22691f;
  const float INV_B   = 1.0f / (-CURVE_B);

  float g_R0_kohm = -1.0;
  float g_ema_ppm = -1.0;
  unsigned long g_bootTime = 0;
  bool g_warmupDone = false;

  float readVoltage_mV(int n) {
    long sum = 0;
    for (int i = 0; i < n; i++) { sum += analogReadMilliVolts(SENSOR_PIN); delay(5); }
    return (float)sum / n;
  }

  float voltageToRs_kohm(float vout_mV) {
    if (vout_mV >= VCC_MV - 1.0) return 0.0001;
    if (vout_mV < 1.0) vout_mV = 1.0;
    return RL_KOHM * (VCC_MV - vout_mV) / vout_mV;
  }

  // No temp/humidity correction here -- MiCS-5524's datasheet doesn't
  // publish one (confirmed earlier), and this fit doesn't include it either.
  float ratioToPPM(float ratio) {
    if (ratio <= 0.0001f) ratio = 0.0001f;
    float ppm = pow(CURVE_A / ratio, INV_B);

    if (ppm < PPM_MIN_VALID) {
      ppm = PPM_MIN_VALID;
    } else if (ppm > PPM_MAX_VALID) {
      Serial.println(F("[NH3 WARNING] Reading above the power-law fit's validated range -- extrapolating past measured data."));
      ppm = PPM_MAX_VALID;
    }
    return ppm;
  }

  bool calibrateR0() {
    if (!g_warmupDone) { Serial.println(F("[NH3 CAL REFUSED] still warming up")); return false; }
    float sumRs = 0; int valid = 0;
    for (int i = 0; i < CALIBRATION_SAMPLES; i++) {
      float rs = voltageToRs_kohm(readVoltage_mV(1));
      if (rs > 0.001 && rs < 100000.0) { sumRs += rs; valid++; }
      delay(20);
    }
    if (valid < CALIBRATION_SAMPLES/2) { Serial.println(F("[NH3 CAL FAILED]")); return false; }
    g_R0_kohm = sumRs / valid;
    prefs.putFloat("nh3_r0", g_R0_kohm);
    Serial.print(F("NH3 calibrated. R0=")); Serial.println(g_R0_kohm, 4);
    return true;
  }

  float getPPM() {
    if (!g_warmupDone) return -2.0;
    if (g_R0_kohm <= 0.0) return -1.0;
    float ratio = voltageToRs_kohm(readVoltage_mV(SAMPLES_PER_READING)) / g_R0_kohm;
    float ppm = ratioToPPM(ratio);
    g_ema_ppm = (g_ema_ppm < 0) ? ppm : (EMA_ALPHA*ppm + (1.0-EMA_ALPHA)*g_ema_ppm);
    return g_ema_ppm;
  }

  void begin() {
    analogSetPinAttenuation(SENSOR_PIN, ADC_11db);
    g_R0_kohm = prefs.getFloat("nh3_r0", -1.0);
    g_bootTime = millis();
  }

  void updateWarmup() {
    if (!g_warmupDone && millis() - g_bootTime >= WARMUP_TIME_MS) {
      g_warmupDone = true;
      Serial.println(F("NH3 warm-up complete."));
    }
  }
}

// ---------------------- PROPANE (digitized power-law fit) ----------------------
// Rs/R0 = 19.29803 * ppm^(-0.59052), R²=0.993 -- strong fit, points span
// ppm 3116.76-15215.12. Same caveats as NH3 above.
namespace Propane {
  const float VCC_MV  = 3300.0;   // VERIFY
  const float RL_KOHM = 10.0;     // VERIFY

  const int SENSOR_PIN = 34;      // placeholder -- pick a real free ADC1 pin, distinct from all other gas namespaces

  const unsigned long WARMUP_TIME_MS = 120000;
  const float PPM_MIN_VALID = 3116.76;
  const float PPM_MAX_VALID = 15215.12;

  const float CURVE_A = 19.29803f;
  const float CURVE_B = -0.59052f;
  const float INV_B   = 1.0f / (-CURVE_B);

  float g_R0_kohm = -1.0;
  float g_ema_ppm = -1.0;
  unsigned long g_bootTime = 0;
  bool g_warmupDone = false;

  float readVoltage_mV(int n) {
    long sum = 0;
    for (int i = 0; i < n; i++) { sum += analogReadMilliVolts(SENSOR_PIN); delay(5); }
    return (float)sum / n;
  }

  float voltageToRs_kohm(float vout_mV) {
    if (vout_mV >= VCC_MV - 1.0) return 0.0001;
    if (vout_mV < 1.0) vout_mV = 1.0;
    return RL_KOHM * (VCC_MV - vout_mV) / vout_mV;
  }

  float ratioToPPM(float ratio) {
    if (ratio <= 0.0001f) ratio = 0.0001f;
    float ppm = pow(CURVE_A / ratio, INV_B);

    if (ppm < PPM_MIN_VALID) {
      ppm = PPM_MIN_VALID;
    } else if (ppm > PPM_MAX_VALID) {
      Serial.println(F("[PROPANE WARNING] Reading above the power-law fit's validated range -- extrapolating past measured data."));
      ppm = PPM_MAX_VALID;
    }
    return ppm;
  }

  bool calibrateR0() {
    if (!g_warmupDone) { Serial.println(F("[PROPANE CAL REFUSED] still warming up")); return false; }
    float sumRs = 0; int valid = 0;
    for (int i = 0; i < CALIBRATION_SAMPLES; i++) {
      float rs = voltageToRs_kohm(readVoltage_mV(1));
      if (rs > 0.001 && rs < 100000.0) { sumRs += rs; valid++; }
      delay(20);
    }
    if (valid < CALIBRATION_SAMPLES/2) { Serial.println(F("[PROPANE CAL FAILED]")); return false; }
    g_R0_kohm = sumRs / valid;
    prefs.putFloat("propane_r0", g_R0_kohm);
    Serial.print(F("Propane calibrated. R0=")); Serial.println(g_R0_kohm, 4);
    return true;
  }

  float getPPM() {
    if (!g_warmupDone) return -2.0;
    if (g_R0_kohm <= 0.0) return -1.0;
    float ratio = voltageToRs_kohm(readVoltage_mV(SAMPLES_PER_READING)) / g_R0_kohm;
    float ppm = ratioToPPM(ratio);
    g_ema_ppm = (g_ema_ppm < 0) ? ppm : (EMA_ALPHA*ppm + (1.0-EMA_ALPHA)*g_ema_ppm);
    return g_ema_ppm;
  }

  void begin() {
    analogSetPinAttenuation(SENSOR_PIN, ADC_11db);
    g_R0_kohm = prefs.getFloat("propane_r0", -1.0);
    g_bootTime = millis();
  }

  void updateWarmup() {
    if (!g_warmupDone && millis() - g_bootTime >= WARMUP_TIME_MS) {
      g_warmupDone = true;
      Serial.println(F("Propane warm-up complete."));
    }
  }
}
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
void loop() {
  H2S::updateWarmup();
  H2::updateWarmup();
  CH4::updateWarmup();
  CO::updateWarmup();
  NH3::updateWarmup();
  Propane::updateWarmup();

  if (Serial.available()) {
    char c = Serial.read();
    if (c == 's' || c == 'S') H2S::calibrateR0();
    if (c == 'h' || c == 'H') H2::calibrateR0();
    if (c == 'c' || c == 'C') CH4::calibrateR0();
    if (c == 'o' || c == 'O') CO::calibrateR0();
    if (c == 'n' || c == 'N') NH3::calibrateR0();
    if (c == 'p' || c == 'P') Propane::calibrateR0();
  }

  unsigned long now = millis();
  if (now - g_lastSampleTime >= SAMPLE_INTERVAL_MS) {
    g_lastSampleTime = now;
    DhtReading d = readDHT();

    float h2sPpm = H2S::getPPM(d);
    float h2Ppm  = H2::getPPM(d);
    float ch4Ppm = CH4::getPPM(d);
    float coPpm  = CO::getPPM();
    float nh3Ppm = NH3::getPPM();
    float propPpm = Propane::getPPM();

    g_disp_h2s = h2sPpm; g_disp_h2 = h2Ppm; g_disp_ch4 = ch4Ppm;
    g_disp_co = coPpm; g_disp_nh3 = nh3Ppm; g_disp_prop = propPpm;

    Serial.printf("T=%.1fC H=%.1f%% | H2S: %s | H2: %s | CH4: %s | CO: %s | NH3: %s | Propane: %s\n",
      d.tempC, d.rh,
      (h2sPpm  == -2.0) ? "warming up" : (h2sPpm  == -1.0) ? "not calibrated" : (h2sPpm  == -3.0) ? "DHT fail" : String(h2sPpm,2).c_str(),
      (h2Ppm   == -2.0) ? "warming up" : (h2Ppm   == -1.0) ? "not calibrated" : (h2Ppm   == -3.0) ? "DHT fail" : (h2Ppm == -4.0) ? "curve not digitized" : String(h2Ppm,2).c_str(),
      (ch4Ppm  == -2.0) ? "warming up" : (ch4Ppm  == -1.0) ? "not calibrated" : (ch4Ppm  == -3.0) ? "DHT fail" : String(ch4Ppm,2).c_str(),
      (coPpm   == -2.0) ? "warming up" : (coPpm   == -1.0) ? "not calibrated" : String(coPpm,2).c_str(),
      (nh3Ppm  == -2.0) ? "warming up" : (nh3Ppm  == -1.0) ? "not calibrated" : String(nh3Ppm,2).c_str(),
      (propPpm == -2.0) ? "warming up" : (propPpm == -1.0) ? "not calibrated" : String(propPpm,2).c_str()
    );
  }
  updateOLED();
}

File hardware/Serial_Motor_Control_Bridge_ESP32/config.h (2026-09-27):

#ifndef CONFIG_H_
#define CONFIG_H_

#define USE_BASE 

#define USE_GENERIC_MOTOR_DRIVER   // Motor drivers with 1 Direction Pin(INA) and 1 PWM(ENABLE) pin.

#define INDIVIDUAL_PID_GAINS     // Use specific PID coefficients for each motor
//#define IDENTICAL_PID_GAINS     // Use identical PID coefficients for each motor

/* Serial port baud rate */
#define BAUDRATE 115200
#define PID_RATE 30 // Hz
#define MAX_PWM 255


/* PID Parameters */
#ifdef INDIVIDUAL_PID_GAINS    
    #define KP_RIGHT 20
    #define KD_RIGHT 12
    #define KI_RIGHT 0
    #define KO_RIGHT 30

    #define KP_LEFT 18
    #define KD_LEFT 12
    #define KI_LEFT 0
    #define KO_LEFT 30
#endif

#ifdef IDENTICAL_PID_GAINS  
    #define KP 20
    #define KD 12
    #define KI 0
    #define KO 50
#endif


/* Encoder Interrupts */
#define encoder0PinA 32      // encoder b Left
#define encoder0PinB 35      // encoder a left

#define encoder1PinA 34     // encoder b right
#define encoder1PinB 33     // encoder a right


/* Motor Driver Interrupts */
#ifdef USE_GENERIC_MOTOR_DRIVER
    //#define RIGHT_MOTOR_ENA  14    // PWM
    #define RIGHT_MOTOR_IN1  14    // direction
    #define RIGHT_MOTOR_IN2  25    // direction

    //#define LEFT_MOTOR_ENB   27    // PWM
    #define LEFT_MOTOR_IN3   26    // direction  ← pick free GPIO
    #define LEFT_MOTOR_IN4   27    // direction  ← pick free GPIO
#endif

#endif

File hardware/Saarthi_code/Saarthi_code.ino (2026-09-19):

/* ============================================================
   RATH SAARTHI MUKUT - ESP-NOW Alert Node
   ------------------------------------------------------------
   IDENTICAL code for every board. The ONLY line you change
   before uploading to a new board is NODE_ID below.

   What this does:
   - Reads MQ4 (methane) and MQ7 (CO) gas levels in PPM
   - Reads MPU6050 accelerometer to detect abnormal vibration
   - Prints ALL live readings to Serial Monitor every loop,
     so you can watch real values for debugging/calibration.
   - Does NOT transmit raw sensor data over ESP-NOW.
     It only transmits a single alert packet (1 char + MAC)
     when a value crosses its safety threshold, to keep
     the wireless payload minimal.
   - Uses a hardcoded "topology table": each node already
     knows which MAC address to send its alert to. You fill
     this in once, and it doesn't change per-board (only
     NODE_ID changes).
   ============================================================ */

#include <esp_now.h>
#include <WiFi.h>
#include <Wire.h>

// ============================================================
// CHANGE ONLY THIS LINE PER BOARD BEFORE UPLOADING
// ============================================================
#define NODE_ID 1        // Node 1 on board A, Node 2 on board B, etc.

// ============================================================
// TOPOLOGY TABLE  (fill in real MAC addresses)
// ------------------------------------------------------------
// Index = NODE_ID - 1. This tells each node WHERE to send its
// own alert packets. Get a board's MAC from its own Serial
// Monitor at boot ("This Node's MAC: ..."), then hardcode it
// into the table on the OTHER board(s).
// This table is the same in every uploaded file -- only the
// NODE_ID macro above differs per board.
// ============================================================
uint8_t nextHopTable[][6] = {
  /* index 0 = Node 1 sends its alerts to -> */ {0x5C, 0x01, 0x3B, 0x73, 0x48, 0x04}, // <-- fill with Node 2's MAC
  /* index 1 = Node 2 sends its alerts to -> */ {0x00, 0x00, 0x00, 0x00, 0x00, 0x00}  // <-- fill with Node 1's MAC
};

// ============================================================
// PIN CONFIG
// ============================================================
#define MQ4_PIN 34   // Methane sensor analog pin (through voltage divider)
#define MQ7_PIN 35   // CO sensor analog pin (through voltage divider)
// MPU6050 uses I2C -> default ESP32 pins: SDA = GPIO21, SCL = GPIO22

// ============================================================
// VOLTAGE DIVIDER CORRECTION
// ------------------------------------------------------------
// R1 = 18k, R2 = 27k -> ratio = R2 / (R1+R2) = 0.6
// This scales the sensor's ~5V AOUT swing down to a safe
// ~3.0V max for the ESP32 ADC. We must UNDO this ratio in
// code to recover the true sensor voltage before doing any
// gas-concentration math.
// ============================================================
const float DIVIDER_RATIO = 0.6;
const float ADC_VREF      = 3.3;   // ESP32 ADC reference voltage
const float SENSOR_VCC    = 5.0;   // Actual supply voltage to the MQ sensor's internal load circuit
const float RL            = 10.0;  // Load resistor on the MQ sensor module (check your module's datasheet)

// ============================================================
// GAS SENSOR CURVE CONSTANTS (approximate, from datasheets)
// Recalibrate MQ4_RO / MQ7_RO for your specific sensor units
// (measured resistance in clean air).
// ============================================================
float MQ4_RO = 10.0;
float MQ7_RO = 10.0;
const float MQ4_A = 1012.7;
const float MQ4_B = -2.786;
const float MQ7_A = 99.042;
const float MQ7_B = -1.518;

// ============================================================
// SAFETY THRESHOLDS -- PLACEHOLDERS
// Replace these with the actual limits from your safety report.
// ============================================================
const float MQ4_THRESHOLD_PPM     = 5000.0; // methane danger level (placeholder)
const float MQ7_THRESHOLD_PPM     = 50.0;   // CO exposure limit in ppm (placeholder)
const float VIBRATION_THRESHOLD_G = 0.3;    // acceptable deviation from 1g baseline

// Hysteresis margin so an alert doesn't spam on/off right at
// the threshold boundary. Value must drop below 90% of the
// threshold before the alert is allowed to fire again.
const float HYSTERESIS_FACTOR = 0.9;

// ============================================================
// MPU6050 REGISTERS (raw I2C access, no external library needed)
// ============================================================
#define MPU_ADDR       0x68
#define MPU_PWR_MGMT_1 0x6B
#define MPU_ACCEL_XOUT 0x3B

// ============================================================
// ALERT PACKET -- deliberately minimal payload
// ============================================================
typedef struct {
  uint8_t nodeId;     // which node detected the problem
  uint8_t mac[6];     // MAC address of the detecting node
  char alertCode;     // 'G' = MQ4 methane, 'C' = MQ7 CO, 'V' = vibration/seismic
} alert_message;

alert_message outgoingAlert;
alert_message incomingAlert;
esp_now_peer_info_t peerInfo;

// Latches so each alert type only fires once per breach event,
// not every single loop iteration while still over threshold.
bool mq4AlertActive = false;
bool mq7AlertActive = false;
bool vibAlertActive = false;

// ============================================================
// Send a minimal alert packet to this node's designated next hop
// ============================================================
void sendAlert(char code) {
  outgoingAlert.nodeId = NODE_ID;
  WiFi.macAddress(outgoingAlert.mac);
  outgoingAlert.alertCode = code;

  uint8_t *targetMac = nextHopTable[NODE_ID - 1];
  esp_err_t result = esp_now_send(targetMac, (uint8_t *)&outgoingAlert, sizeof(outgoingAlert));

  Serial.print("ALERT SENT [");
  Serial.print(code);
  Serial.println(result == ESP_OK ? "] -> send queued OK" : "] -> send FAILED");
}

// ============================================================
// ESP-NOW send callback (newer core signature: wifi_tx_info_t*)
// ============================================================
void OnDataSent(const wifi_tx_info_t *tx_info, esp_now_send_status_t status) {
  Serial.print("Delivery Status: ");
  Serial.println(status == ESP_NOW_SEND_SUCCESS ? "Success" : "Fail");
}
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

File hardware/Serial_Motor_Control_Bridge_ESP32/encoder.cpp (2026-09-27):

#include "encoder.h"

volatile long encoder0Pos = 0;    // encoder 1
volatile long encoder1Pos = 0;    // encoder 2

void doEncoderA(){  
  // look for a low-to-high on channel A
  if (digitalRead(encoder0PinA) == HIGH) { 
    // check channel B to see which way encoder is turning
    if (digitalRead(encoder0PinB) == LOW) {  
      encoder0Pos = encoder0Pos - 1;         // CW
    } 
    else {
      encoder0Pos = encoder0Pos + 1;         // CCW
    }
  }
  else   // must be a high-to-low edge on channel A                                       
  { 
    // check channel B to see which way encoder is turning  
    if (digitalRead(encoder0PinB) == HIGH) {   
      encoder0Pos = encoder0Pos - 1;          // CW
    } 
    else {
      encoder0Pos = encoder0Pos + 1;          // CCW
    }
  }
}

void doEncoderB(){  
  // look for a low-to-high on channel B
  if (digitalRead(encoder0PinB) == HIGH) {   
   // check channel A to see which way encoder is turning
    if (digitalRead(encoder0PinA) == HIGH) {  
      encoder0Pos = encoder0Pos - 1;         // CW
    } 
    else {
      encoder0Pos = encoder0Pos + 1;         // CCW
    }
  }
  // Look for a high-to-low on channel B 
  else { 
    // check channel B to see which way encoder is turning // 
    if (digitalRead(encoder0PinA) == LOW) {   
      encoder0Pos = encoder0Pos - 1;          // CW
    } 
    else {
      encoder0Pos = encoder0Pos + 1;          // CCW
    }
  }
}

// ************** encoder 2 *********************

void doEncoderC(){  
  // look for a low-to-high on channel A
  if (digitalRead(encoder1PinA) == HIGH) { 
    // check channel B to see which way encoder is turning
    if (digitalRead(encoder1PinB) == LOW) {  
      encoder1Pos = encoder1Pos + 1;         // CW
    } 
    else {
      encoder1Pos = encoder1Pos - 1;         // CCW
    }
  }
  else   // must be a high-to-low edge on channel A                                       
  {  
    if (digitalRead(encoder1PinB) == HIGH) {   
      encoder1Pos = encoder1Pos + 1;          // CW
    } 
    else {
      encoder1Pos = encoder1Pos - 1;          // CCW
    }
  }
}

void doEncoderD(){  
  // look for a low-to-high on channel B
  if (digitalRead(encoder1PinB) == HIGH) {   
   // check channel A to see which way encoder is turning
    if (digitalRead(encoder1PinA) == HIGH) {  
      encoder1Pos = encoder1Pos + 1;         // CW
    } 
    else {
      encoder1Pos = encoder1Pos - 1;         // CCW
    }
  }
  // Look for a high-to-low on channel B
  else { 
    // check channel B to see which way encoder is turning  
    if (digitalRead(encoder1PinA) == LOW) {   
      encoder1Pos = encoder1Pos + 1;          // CW
    } 
    else {
      encoder1Pos = encoder1Pos - 1;          // CCW
    }
  }
}

void init_encoders(){
  pinMode(encoder0PinA, INPUT_PULLUP);    // encoder pins
  pinMode(encoder0PinB, INPUT);

  pinMode(encoder1PinA, INPUT); 
  pinMode(encoder1PinB, INPUT_PULLUP);

  attachInterrupt(encoder0PinA, doEncoderA, CHANGE);
  attachInterrupt(encoder0PinB, doEncoderB, CHANGE); 

  attachInterrupt(encoder1PinA, doEncoderC, CHANGE);
  attachInterrupt(encoder1PinB, doEncoderD, CHANGE); 
}

long readEncoder(int i) {
    if (i == LEFT) return encoder0Pos;
    else return encoder1Pos;
  }

/* Wrap the encoder reset function */
void resetEncoder(int i) {
  if (i == LEFT){
    encoder0Pos=0L;
    return;
  } else { 
    encoder1Pos=0L;
    return;
  }
}

/* Wrap the encoder reset function */
void resetEncoders() {
  resetEncoder(LEFT);
  resetEncoder(RIGHT);
}

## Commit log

2026-09-26 Added gas sensor codes
2026-09-27 feat: Rover CAD model
    [Camera_frame.stl, Front_gear_sprocket.stl, Gas_Bottom.stl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]
2026-09-27 feat: Rover workspace
    [robot_controller_example.yaml]
2026-09-27 feat: ESP32 Serial motor control bridge
2026-10-02 Added prototype images
2026-10-02 prototype images added
2026-10-02 Sarthi PCB Design
    [SIH Sarthi.kicad_pcb, SIH Sarthi.kicad_sch]
